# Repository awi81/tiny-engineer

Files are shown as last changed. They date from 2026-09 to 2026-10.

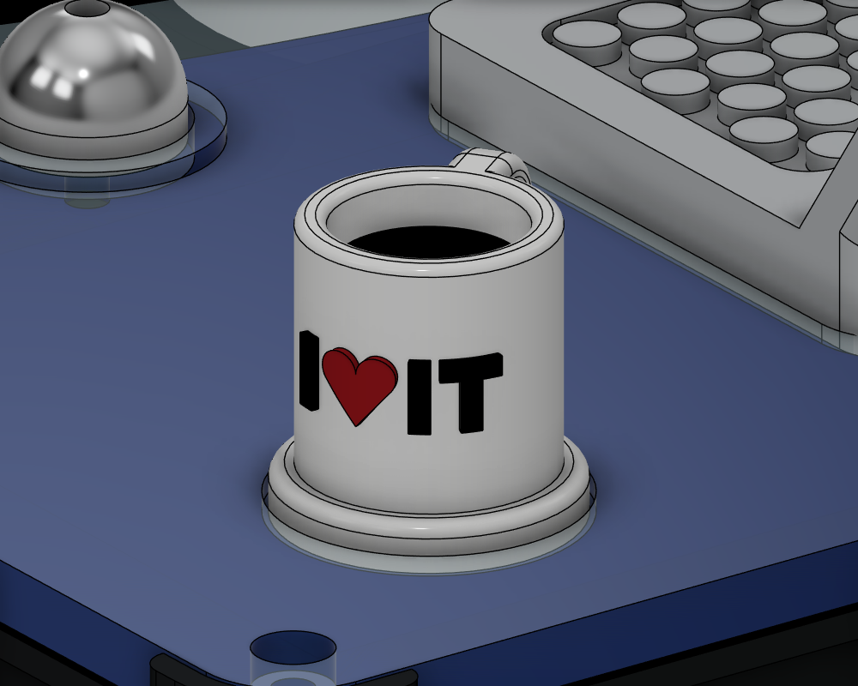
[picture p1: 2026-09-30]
mein-build/farben/variante2-tasse.png

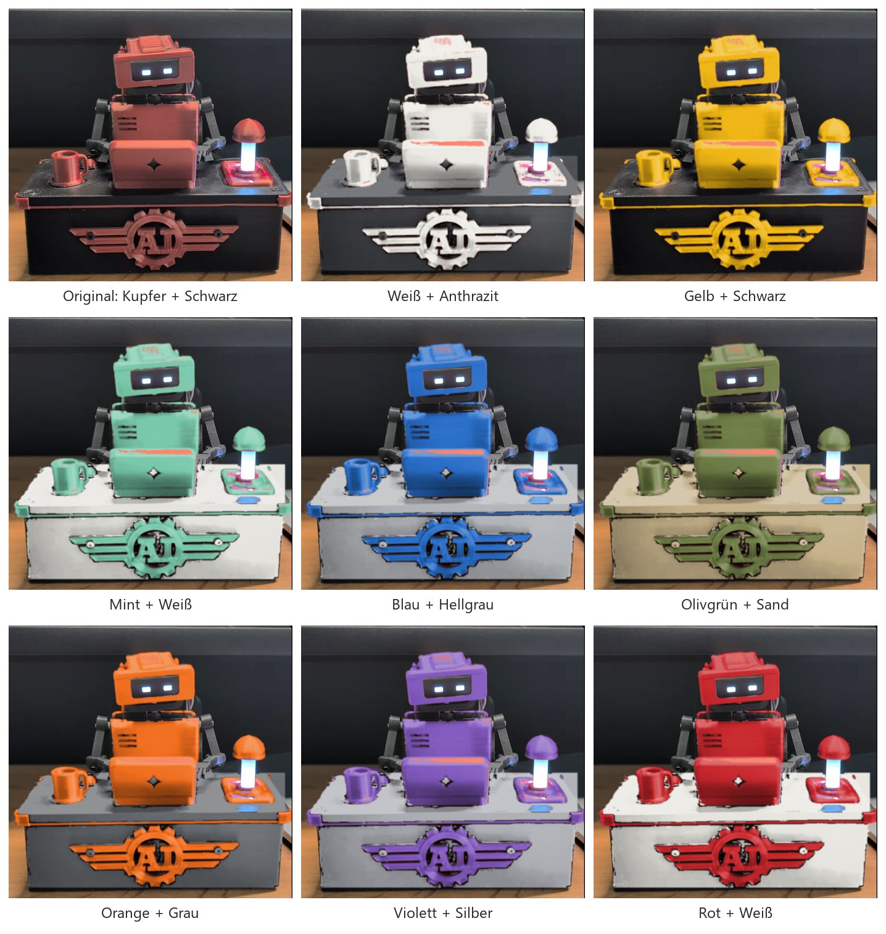
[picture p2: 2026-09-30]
mein-build/farben/farbideen.jpg

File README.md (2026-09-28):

# Tiny Engineer

> Give your AI coding agent a body.

Tiny Engineer demo

Tiny Engineer is an open-source, 3D-printable desktop robot that physically acts out what an AI coding agent is doing: reading, thinking, coding, finishing tasks (with a audio cue). It runs on an ESP32 over Wi-Fi and exposes a simple REST API, so any tool that can make an HTTP request can drive it.

**[Watch the demo](https://youtu.be/RX_QRxdXMjg) · [Build your own](#build-your-own) · [How it works](#how-it-works) · [API](docs/api.md)**

## Why?

AI coding agents increasingly spend long stretches working on their own. I wanted to see what mine was doing without staring at the IDE.

So I built a slightly ridiculous desk robot: instead of another spinner or status line, there is a tiny teammate sitting next to me, visibly reading, thinking, and typing while the agent works.

## How it works

How Tiny Engineer works

An AI agent works; an integration turns that into events; the robot’s REST API on your LAN receives them; the hardware moves and reacts.

**How it connects**

- **Cursor** — Cursor Agent → Cursor hooks → `tiny-engineer-cursor` script → HTTP over Wi-Fi
- **Antigravity CLI** — Antigravity Agent → lifecycle hooks → `tiny-engineer-antigravity` script → HTTP over Wi-Fi
- **Claude Code** — Claude Code → project hooks → `tiny-engineer-claude-code` script → HTTP over Wi-Fi
- **Bring your own** — Codex or any other agent → your script/plugin/app → HTTP REST

All hit the same Tiny Engineer REST API (`/anim`). The ESP32-C3 runs that API, robot logic, and animations, then drives (and plays audio):

| Hardware | Role |
| --- | --- |
| PCA9685 → 5× servos | Head / neck, hands / body |
| Waveshare 0.91inch OLED (SSD1306) | Status, face, info |
| MAX98357A → speaker | Audio |

Cursor is one example client, not the architecture. Details: [Cursor hooks](docs/hooks.md) · [any integration](docs/integration.md) · [HTTP API](docs/api.md)

## Build your own

**Start here:** [docs/getting-started.md](docs/getting-started.md) — thin checklist (shop → print → wire → flash → assemble → wizard → prove → agent).

New to hardware? Optional skim of **[From Code to Circuits](docs/hardware-for-software-engineers/README.md)** — then return to the checklist.

## Hardware overview

Major pieces (exact models and counts in the BOM):

| Role | Part | Qty |
| --- | --- | --- |
| Main Controller | [Waveshare ESP32-C3-Zero](https://www.waveshare.com/esp32-c3-zero.htm) | 1 |
| Servo Controller PWM | [Adafruit PCA9685](https://www.adafruit.com/product/815) | 1 |
| Actuators | Analog micro servos — **Tower Pro SG90 recommended**; Feetech FS0307 for a compact build; Parametrically designed for any standard micro servos | 5 |
| Display | [Waveshare 0.91inch OLED Module](https://www.waveshare.com/0.91inch-oled-module.htm) (SSD1306, 128×32, I2C) | 1 |
| Audio | [MAX98357A](https://www.adafruit.com/product/3006) + [8 Ω / 1 W speaker](https://www.adafruit.com/product/3923) | 1 + 1 |
| USB / power | [Adafruit 5993 USB-C breakout](https://www.adafruit.com/product/5993); **5 V / ≥2 A** supply | 1 |
| Structure | 3D-printed parts | — |

Complete inventory and limits: [docs/hardware/components.md](docs/hardware/components.md). What to buy (cart + which servo): [docs/shopping.md](docs/shopping.md).

> **Interested in an assembled Main Board?**  
> An integrated PCB that replaces most of the separate electronics modules and wiring is in development. If you'd be interested in getting a fully assembled board, [let me know in the community interest check](https://github.com/jamro/tiny-engineer/discussions/50).

## Quick start

Firmware is Arduino on [PlatformIO](https://platformio.org/). From the project root:

```bash
pio run                 # build
pio run -t upload       # flash firmware + LittleFS
pio device monitor      # serial (115200)
```

If servos move but audio is silent, run `pio run -t uploadfs` once.

**Wi-Fi (first boot):** join `TinyEngineer-XXXX`, open `http://192.168.4.1/config`. Wizard: servos, screen orientation, RGB LED, speaker, then a **2.4 GHz** network. OLED shows the join-AP steps.

**Web UI:** `http://tiny-engineer.local/` (or the IP on the OLED) — settings, hardware tests, animations.

**Make it move:**

```bash
curl -X POST "http://tiny-engineer.local/anim?name=ring"
```

Full route list: [docs/api.md](docs/api.md). Settings: [docs/settings.md](docs/settings.md).

## AI integrations

Anything that can `POST` over HTTP can drive the robot:

```bash
curl -X POST "http://tiny-engineer.local/anim?name=typing"
```

Useful `name` values: `typing`, `reading`, `thinking`, `ring`, `welcome`, `wakeup`, `sleep`, `attention`, `error`, `abort`, `dead`, `none`.

Cursor projects can map agent events to poses via hooks — [docs/hooks.md](docs/hooks.md). Broader patterns and examples: [docs/integration.md](docs/integration.md). Optional extra: sleep/wake when you lock or unlock a Mac — [docs/macos-lock-unlock.md](docs/macos-lock-unlock.md).

## Documentation

| Goal | Doc |
| --- | --- |
| Build end-to-end | [docs/getting-started.md](docs/getting-started.md) |
| Flash firmware | [docs/flash.md](docs/flash.md) |
| Parts / cart | [docs/shopping.md](docs/shopping.md) |
| Wiring / power | [docs/hardware/README.md](docs/hardware/README.md) |
| Printable parts | [3d_models/README.md](3d_models/README.md) |
| Optional mods | [mods/README.md](mods/README.md) |
| Assemble printed parts | [docs/3d/assembly.md](docs/3d/assembly.md) |
| Resize CAD for another servo | [docs/3d/parametric-design.md](docs/3d/parametric-design.md) |
| Servo axes / safe ranges | [docs/robot-movement.md](docs/robot-movement.md) |
| HTTP API | [docs/api.md](docs/api.md) |
| Settings | [docs/settings.md](docs/settings.md) |
| Cursor hooks | [docs/hooks.md](docs/hooks.md) |
| Any IDE / REST | [docs/integration.md](docs/integration.md) |
| Firmware / package tests | [docs/testing.md](docs/testing.md) |
| Full index | [docs/README.md](docs/README.md) |

## Build one, break one, share it

Print it, wire it, change the CAD, swap animations, or hook up a different agent. Issues and PRs welcome — especially new integrations. See [CONTRIBUTING.md](CONTRIBUTING.md). Vulnerabilities: [SECURITY.md](SECURITY.md). Conduct: [CODE_OF_CONDUCT.md](CODE_OF_CONDUCT.md).

Tiny Engineer

## License

- **Software** (firmware, integrations, scripts, documentation) — [MIT](LICENSE)
- **Hardware designs** (CAD source and printables in [`3d_models/`](3d_models/) and under [`mods/*/3d_models/`](mods/); KiCad PCBs in [`hardware/`](hardware/)) — [CERN-OHL-S-2.0](3d_models/LICENSE)

See [LICENSING.md](LICENSING.md) for scope and effective date. The **Tiny Engineer** name and logo are not licensed — see [TRADEMARK.md](TRADEMARK.md).

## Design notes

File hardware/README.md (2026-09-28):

# Hardware (PCB)

KiCad PCB projects for Tiny Engineer.

Boards live under `boards/<board-name>/`. Prefer the same name for the directory and the KiCad project.

| Board | Role |
| --- | --- |
| [`main-control-board`](boards/main-control-board/) | Draft main board: PCA9685, MAX98357A, and USB-C on the board; ESP32-C3-Zero plugs into two sockets |

Contribution rules, KiCad version, what to commit, ERC/DRC, and PR expectations: [docs/pcb.md](../docs/pcb.md). Pre-PR checklist: [docs/pcb.md#checklist](../docs/pcb.md#checklist). Critical net checklist: [docs/pcb.md#expected-nets-yml](../docs/pcb.md#expected-nets-yml). Local/CI checks: `python3 scripts/check_pcb.py` (KiCad 10) — [docs/testing.md](../docs/testing.md).

This tree is KiCad source only. Robot electrical reference (pinout, wiring, BOM) is [`docs/hardware/`](../docs/hardware/README.md). Firmware drivers are `src/hardware/`.

## License

Board sources in `boards/` are [CERN-OHL-S-2.0](LICENSE). See [NOTICE](NOTICE) for copyright, Source Location, and product notice requirements.

This README is software documentation and remains under the MIT License — [LICENSING.md](../LICENSING.md).

The **Tiny Engineer** name and logo are not licensed — [TRADEMARK.md](../TRADEMARK.md).

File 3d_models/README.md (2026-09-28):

# 3D models

Printable parts and source CAD for the Tiny Engineer desk robot.

## Source CAD (edit / resize)

The full assembly — all components composed — lives in [`cad/TinyEngineer.f3d`](cad/TinyEngineer.f3d) (Autodesk Fusion). Open that file to adjust the model or adapt it to different hardware sizing (e.g. different servos). Parametric servo sizes and the Fusion add-in: [docs/3d/parametric-design.md](../docs/3d/parametric-design.md).

**Adding a new part** (parametric rules, timeline, `PRINT_LAYOUT`, Servo Configurator, export, optional mods): [docs/3d/adding-parts.md](../docs/3d/adding-parts.md). Optional / community mods: [`mods/`](../mods/).

## Printables

Individual parts are exported under [`parts/{servo_id}/`](parts/). Match the folder to the servos you bought ([which servo](../docs/shopping.md)). `stl/` next to `3mf/` is the same mesh in binary STL. `step/` next to those is CAD interchange (BRep STEP), not a printable mesh for a home slicer.

Two ways to get the mechanical set (same place in the build path):

- **Print yourself** — use the **`.3mf` files in `parts/sg90/3mf/`**, **`parts/fs0307/3mf/`**, or **`parts/hd1370a/3mf/`**. Ready to print in an orientation that does not need supports. **PLA** or **PETG**. Start with [Print first](#print-first).
- **No printer?** — order the aggregated sets from a third-party service: [order printed parts](../docs/3d/order-parts.md). Orders are at your own risk; fit can vary by provider and design revision.

### Print first

**Home printers only.** Print these two small testers from that folder **before** the rest of the set. Do not print the full robot until both fit. Skip this step when ordering from a service (testers alone are rarely worth the min fee + shipping).

1. **`ServoSizingTester.3mf`** — seat a real servo; do not force it. The body should slide, tabs sit, holes line up, and the shaft should have clearance. Tight or loose → sand/ream, or adjust servo CAD params ([parametric design](../docs/3d/parametric-design.md)).
2. **`ScrewSizingTest.3mf`** — M2 screw pilot-hole tolerance. Each hole is marked with its diameter. Drive an M2 screw into each hole and pick the tightest size that still cuts a thread (does not spin freely / slide through). Set Fusion user parameter `screw_thread_diameter` to that marked value, then re-export before printing structural parts. Details: [M2 screw holes](../docs/3d/parametric-design.md#m2-screw-holes).

Assembly uses **M2 screws** that thread directly into the printed PLA/PETG — no glue, no heat-set inserts. Easy to dismount and modify later. Buyer cart (electronics + screw qty + supply): [docs/shopping.md](../docs/shopping.md). Overall build order: [docs/getting-started.md](../docs/getting-started.md). Mechanical procedure: [docs/3d/assembly.md](../docs/3d/assembly.md). Per-step lengths: [screw list](#screws) below.

### Screws

**Spec:** M2 thread-forming (self-tapping) screws for plastic, **pan-head or button-head** — there are no counterbores/countersinks in any part, so heads sit on the plastic surface. CAD default pilot is **2.1 mm** (Fusion user parameter `screw_thread_diameter`); if your `ScrewSizingTest` winner differs, re-export at that diameter before printing structural parts. Details: [M2 screw holes](../docs/3d/parametric-design.md#m2-screw-holes).

**One BOM for every servo preset** (`parts/sg90/`, `parts/fs0307/`, `parts/hd1370a/`, …). Printed parts scale with the servo choice, but the lengths below are the reference list for all of them — including smaller models for smaller servos. Buy quantities: [docs/shopping.md](../docs/shopping.md). Pilots are cut as deep as practical so nearby lengths often work too; if you already have different M2 lengths, test-fit before buying a full set. Per-step placement: [assembly guide](../docs/3d/assembly.md).

**Per robot (qty is source of truth):**

| Item | Qty | Typical use |
| --- | --- | --- |
| M2×4 mm | 8 | Emblem, PCA9685, MAX98357A |
| M2×8 mm | 21 | Hat, Neck↔Head, Chest center (prefer two), Belly↔Chest, LampBase, laptop, mug, Chair↔Desk, elbows |
| M2×16 mm | 15 | Chest side servos, SeatLeft/Right, DeskTop stack, USB-C, Bell |
| M2 nuts | 6 | Neck captured ×1, USB-C ×4, Bell ×1 |
| Servo bag screws | 5 | Neck shaft, Neck↔Head (robot’s left), Belly shaft, both arms |

Prefer **two** M2×8 for the Neck servo in `Chest`; one at the back is enough if space is tight (buy 21 either way). An M2 assortment covering **M2×4–M2×16** is the easy path.

## Parts

Same filenames in each `parts/{servo_id}/3mf/` folder (and matching `stl/` / `step/`):

| File | Role |
| --- | --- |
| `PartsSetA.3mf` | Aggregated copper-color group for [service orders](../docs/3d/order-parts.md) (home print: use individuals below) |
| `PartsSetB.3mf` | Aggregated black-color group for [service orders](../docs/3d/order-parts.md) (home print: use individuals below) |
| `Head.3mf` | Head (pitch) |
| `Neck.3mf` | Neck (yaw) |
| `ForearmLeft.3mf` | Left forearm / hand |
| `ForearmRight.3mf` | Right forearm / hand |
| `UpperArm.3mf` | Upper arm |
| `Chest.3mf` | Chest / torso |
| `Belly.3mf` | Belly |
| `Chair.3mf` | Chair |
| `SeatLeft.3mf` | Left chair seat |
| `SeatRight.3mf` | Right chair seat |
| `Desk.3mf` | Desk structure |
| `DeskTop.3mf` | Desk top surface |
| `DeskPad.3mf` | Desk pad |
| `LaptopCase.3mf` | Miniature laptop body |
| `LaptopScreen.3mf` | Laptop screen |
| `Bell.3mf` | Service bell |
| `LampBase.3mf` | Desk lamp base |
| `LampCap.3mf` | Lamp cap |
| `LampDiffuser.3mf` | Lamp diffuser |
| `LampButton.3mf` | Lamp button |
| `Mug.3mf` | Mug |
| `Coffee.3mf` | Coffee fill |
| `Hat.3mf` | Hat |
| `ServoSizingTester.3mf` | Servo pocket fit tester |
| `ScrewSizingTest.3mf` | M2 screw pilot-hole diameter tester |
| `AiEmblem.3mf` | AI emblem detail |

## Next steps

Return to the build checklist: [docs/getting-started.md](../docs/getting-started.md) ([§2 Print or order](../docs/getting-started.md#2-print-or-order) done). Wire and flash **before** opening the mechanical guide.

1. Wire, then flash: [docs/hardware/wiring.md](../docs/hardware/wiring.md), [docs/flash.md](../docs/flash.md)
2. Assemble in one run: [docs/3d/assembly.md](../docs/3d/assembly.md)
3. Servo axes and safe ranges: [docs/robot-movement.md](../docs/robot-movement.md)
4. Bring-up and failures: [docs/hardware/testing.md](../docs/hardware/testing.md)

## License

CAD source (`.f3d`) in [`cad/`](cad/) and printable parts (`.3mf`) in [`parts/`](parts/) are licensed under [CERN-OHL-S-2.0](LICENSE). See [NOTICE](NOTICE) for copyright, Source Location, and product notice requirements.

Commercial use is allowed. If you modify and distribute Products based on these designs, reciprocal provisions require sharing your Complete Source under the same license. This documentation file is software documentation and remains under the MIT License — see [LICENSING.md](../LICENSING.md).

The **Tiny Engineer** name and logo are not licensed — see [TRADEMARK.md](../TRADEMARK.md).

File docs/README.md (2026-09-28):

# Docs index

Pick a path. Depth lives in the linked pages.

### Building the robot

| You want to… | Start here |
| --- | --- |
| **Build from scratch** (canonical checklist) | [getting-started.md](getting-started.md) |
| **Buy parts** (one cart) | [shopping.md](shopping.md) |
| **Bridge into hardware/electronics** (software engineer background) | [hardware-for-software-engineers/README.md](hardware-for-software-engineers/README.md) — optional parallel reading; safety card lives on the checklist |
| **Assemble printed parts** (mechanical procedure) | [3d/assembly.md](3d/assembly.md) |
| **Flash firmware** | [flash.md](flash.md) |
| **Wire / power detail** | [hardware/wiring.md](hardware/wiring.md) → [hardware/README.md](hardware/README.md) |
| **Print / parts inventory** | [../3d_models/README.md](../3d_models/README.md) |
| **Order printed parts** (no 3D printer) | [3d/order-parts.md](3d/order-parts.md) |
| **Adapt CAD to a different servo** | [3d/parametric-design.md](3d/parametric-design.md) |
| **Add a new CAD / printable part** | [3d/adding-parts.md](3d/adding-parts.md) |
| **Optional mods** | [../mods/README.md](../mods/README.md) |
| **Use with an agent** (robot already on Wi-Fi) | [integration.md](integration.md) · Cursor: [hooks.md](hooks.md) |

### Reference and contribute

| You want to… | Start here |
| --- | --- |
| **Contribute a PCB** (KiCad) | [pcb.md](pcb.md) → [`hardware/`](../hardware/README.md) |
| **HTTP API / settings** | [api.md](api.md); add a setting: [settings.md](settings.md) |
| **Any IDE / scripts** | [integration.md](integration.md) |
| **Firmware / package tests** | [testing.md](testing.md) |
| **AI coding agents (repo rules)** | [AGENTS.md](../AGENTS.md) |
| **Contribute / report a vuln** | [CONTRIBUTING.md](../CONTRIBUTING.md); [SECURITY.md](../SECURITY.md) |

Also: [robot-movement.md](robot-movement.md) (servo axes and safe ranges); optional [macos-lock-unlock.md](macos-lock-unlock.md) (sleep/wake on Mac screen lock).

**Source of truth:** pin constants in firmware (`include/pins.h`); electrical detail in `docs/hardware/`; HTTP shapes in [api.md](api.md). Overall build order: [getting-started.md](getting-started.md).

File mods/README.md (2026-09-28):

# Mods

Optional add-ons for Tiny Engineer. Stock robot parts live in [`3d_models/`](../3d_models/).

A mod can hold models and anything else (notes, images, firmware snippets). Printable geometry and Fusion source stay under that mod’s `3d_models/` folder.

## Layout

```text
mods/<mod_name>/
  README.md              # optional: what it is, non-model notes
  3d_models/
    cad/                 # Fusion source, when the mod has one
    parts/{servo_id}/    # exports; same idea as 3d_models/parts/
  ...                    # anything that is not a model
```

`parts/{servo_id}/` mirrors stock: `3mf/`, `stl/`, and `step/`. Example: [`halloween/`](halloween/).

## Audio

Optional speaker replacements live in `mods/<mod_name>/assets/`. Format matches stock: **44100 Hz, mono, 16-bit PCM**. Firmware still plays `/welcome.wav` and the other root names. The build overlay copies stock [`assets/`](../assets/) first, then overwrites any basename the mod ships. A missing file stays the stock clip.

Set the mod in [`platformio.ini`](../platformio.ini) (`custom_audio_mod = halloween`) and flash with `pio run -t upload`. An empty option keeps the stock image. How to flash: [docs/flash.md](../docs/flash.md).

Clips with phrase marks (`welcome`, `attention`, `error`, `abort`, `dead`) need a sibling `.cue` next to the replacement WAV. `bell` has no marks. A cue without its WAV is rejected. Lines are `key=ms` (`#` comments allowed). `end_ms` must be within 200 ms of the WAV duration, phases must increase, and a blink must sit inside its window. The pack step checks this before the image is built.

Firmware loads `/welcome.cue` (and the other clip names) from LittleFS at boot. A missing or invalid file keeps the stock marks compiled into the firmware. Editing a `.cue` and running `pio run -t uploadfs` changes timing without a gesture-code change.

| Clip | Keys, in phase order |
| --- | --- |
| `welcome` | `greeting_end_ms`, `pause_end_ms`, `question_end_ms`, `end_ms`. Blink: `blink_start_ms`, `blink_end_ms` inside greeting→pause. |
| `attention` | `pst_end_ms`, `human_end_ms`, `end_ms`. Blink inside pst→human. |
| `error` | `uhoh_end_ms`, `human_end_ms`, `problem_end_ms`, `end_ms` |
| `abort` | `fine_end_ms`, `didnt_want_end_ms`, `finish_end_ms`, `end_ms` |
| `dead` | `dense_ms`, `shutdown_ms`, `end_ms` |

## Workflow

Design, timeline, `PRINT_LAYOUT`, export, and checklist: [docs/3d/adding-parts.md](../docs/3d/adding-parts.md).

## Commits

`type(mods): summary`. Name the mod in the summary (`feat(mods): add desk clamp`). One scope for every mod. `feat(mods)` / `fix(mods)` do not version the stock CAD revision. Moving a mod into stock [`3d_models/cad/`](../3d_models/cad/) and [`3d_models/parts/`](../3d_models/parts/) is `feat(cad)`. Full rules: [CONTRIBUTING.md](../CONTRIBUTING.md).

## License

CAD and manufacturing exports under `mods/<mod_name>/3d_models/{cad,parts}/` are [CERN-OHL-S-2.0](../3d_models/LICENSE). See [NOTICE](../3d_models/NOTICE) for warranty and product-notice requirements.

When you distribute a Product based on a mod, cite that licence and use the mod’s own `3d_models` tree as the Source Location (for example `https://github.com/jamro/tiny-engineer/tree/main/mods/halloween/3d_models`).

This README and other files beside `3d_models/` are documentation under the [MIT License](../LICENSE).

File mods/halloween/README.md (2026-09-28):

# Halloween

Optional Halloween mod for Tiny Engineer: a pumpkin head, a lamp, and cauldron pieces. Printable parts and Fusion source are under [`3d_models/`](3d_models/).

## Audio

Alternate speaker clips are in [`assets/`](assets/). The set replaces `welcome`, `attention`, `error`, and `abort`. `bell` and `dead` stay the stock files. Transcripts and cue marks are in [`assets/README.md`](assets/README.md).

Build and flash this overlay with `custom_audio_mod = halloween` in [`platformio.ini`](../../platformio.ini), then `pio run -t upload`. See [docs/flash.md](../../docs/flash.md).

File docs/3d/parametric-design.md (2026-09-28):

# Parametric design (different servo sizes)

[`3d_models/cad/TinyEngineer.f3d`](../../3d_models/cad/TinyEngineer.f3d) is the parametric Fusion source for the robot. Printed pockets, mounting tabs, shaft clearance, and M2 screw pilots are driven by Fusion **user parameters**. Change those values and the assembly rebuilds for a different micro servo or a tighter/looser screw fit.

Presets live in [`servos.json`](../../3d_models/fusion/TinyEngineerTools/servos.json). **TinyEngineer Tools** writes them into the `.f3d`, then exports print meshes under `parts/{servo_id}/3mf/` (and matching `stl/`) plus STEP CAD under `parts/{servo_id}/step/`.

```mermaid
flowchart LR
  json["servos.json presets"]
  cfg["Servo Configurator"]
  f3d["TinyEngineer.f3d user params"]
  parts["parts/servo_id meshes"]
  json --> cfg --> f3d --> parts
```

## Which servo

Servo size sets the size of the **whole robot**. Desk, chair, body, and pockets all scale with the preset. Pick the servo first, then print the matching `parts/{servo_id}/3mf/` folder.

Built-in presets in [`servos.json`](../../3d_models/fusion/TinyEngineerTools/servos.json):

| Model | `servo_id` | When to use |
| --- | --- | --- |
| **Tower Pro SG90** (recommended) | `sg90` | Easiest to buy. Bigger desk — electronics are easier to fit and assemble. |
| **Feetech FS0307** | `fs0307` | More compact. Looks better if you want a smaller robot. |
| **PowerHD HD-1370A** | `hd1370a` | Still supported for backward compatibility. Not the pick for a new build. |

A non-standard servo is fine: measure it, add a preset, run the configurator ([Add a new servo](#add-a-new-servo)). Print parts that match that `servo_id`.

Print matching `parts/{servo_id}/3mf/`: [`sg90`](../../3d_models/parts/sg90/3mf/), [`fs0307`](../../3d_models/parts/fs0307/3mf/), [`hd1370a`](../../3d_models/parts/hd1370a/3mf/).

## Servo parameters

Each preset in `servos.json` is a map of Fusion user-parameter names to expressions such as `"20 mm"`. The configurator ([`servo.py`](../../3d_models/fusion/TinyEngineerTools/servo.py)) writes those into the open design. It refuses names that are not already user parameters in the `.f3d` — do not invent keys.

Servo body dimensions used as Fusion user parameters

### Body and tabs

| Parameter | Meaning |
| --- | --- |
| `servo_body_width` | Body length between the two mounting tabs (tabs not included). |
| `servo_body_height` | Body height, from the mounting-tab plane to the opposite face. |
| `servo_body_depth` | Body thickness (front to back). |
| `servo_mount_width` | How far each mounting tab sticks out from the body. |
| `servo_mount_thickness` | Tab thickness. |

### Gearbox and shaft stack

| Parameter | Meaning |
| --- | --- |
| `servo_gearbox_height` | Gearbox step sitting on the body. |
| `servo_shaft_housing_height` | Boss around the output shaft, above the gearbox. |
| `servo_gearbox_padding` | How far the gearbox / shaft stack is inset from the body edge (the asymmetric “fat” side of typical micro servos). |

### Shaft

| Parameter | Meaning |
| --- | --- |
| `servo_shaft_position` | Distance from the body end to the shaft axis. |
| `servo_shaft_length` | How far the spline shaft sticks out. |
| `servo_shaft_radius` | Shaft radius (not diameter). |

### Mount holes

`servo_mount_hole_radius` is in `servos.json` but not drawn on the diagram.

| Parameter | Meaning |
| --- | --- |
| `servo_mount_hole_depth_offset` | Hole shift along body depth from the tab centerline. |
| `servo_mount_hole_width_offset` | Hole shift along the tab (toward or away from the body). |
| `servo_mount_hole_radius` | Screw-hole radius in the tabs. |

### Not a dimension

| Parameter | Meaning |
| --- | --- |
| `servo_id` | Short lowercase folder id (`hd1370a`, `fs0307`, `sg90`). The configurator writes it; the exporter uses it. |

## M2 screw holes

Assembly uses **M2 screws** that thread directly into the printed PLA/PETG (no heat-set inserts). Pilot-hole size is a Fusion **user parameter**, not a servo preset:

| Parameter | Meaning |
| --- | --- |
| `screw_thread_diameter` | Modeled diameter of M2 self-tapping pilot holes in the printed parts. |

Related (usually leave alone): `screw_head_diameter`, `screw_head_height` — countersink / head clearance for the same fasteners.

`screw_thread_diameter` is **not** in [`servos.json`](../../3d_models/fusion/TinyEngineerTools/servos.json). Change it in Fusion (**Modify → Change Parameters**), then run **Tiny Engineer Parts Exporter** again.

### Why dial it in

Print tolerances vary by printer, material, and slicer. FDM holes often print smaller than modeled, so the CAD default is slightly oversized relative to an M2 major diameter (~2.0 mm). On some printers the hole still comes out large enough that the screw **slides through** instead of cutting a thread — mounting gets loose.

### Use `ScrewSizingTest` first

1. Print [`ScrewSizingTest.3mf`](../../3d_models/README.md#print-first) from your `parts/{servo_id}/3mf/` folder (quick, small).
2. Each hole is labeled with its diameter (about **2.00–2.40 mm** in **0.05 mm** steps).
3. Drive an M2 screw into each hole. Prefer the **tightest** hole that still lets the screw cut a clean thread (firm bite, not free-spinning, not so tight you strip the plastic).
4. Set `screw_thread_diameter` to that labeled value and re-export before printing the full set.

Print [`ServoSizingTester`](../../3d_models/README.md#print-first) in the same “print first” pass for servo pocket fit.

### Recommended / tested values

| Value | When |
| --- | --- |
| **2.1 mm** | CAD default and shipped `parts/*/3mf/` exports. Tested path on a **Creality Ender 3 V3 SE**, PLA, ~0.16 mm layer height ([printing notes](../hardware-for-software-engineers/06-3d-printing-and-mechanical-build.md)). |
| Smaller (e.g. 2.05–2.15 mm) | Pilot too tight to start a thread without cracking — pick from `ScrewSizingTest`. |
| Larger (e.g. 2.25–2.35 mm) | Screws feel loose / slide through on your printer — pick from `ScrewSizingTest`. |

Always trust **your** `ScrewSizingTest` result over the table if they disagree.

## TinyEngineer Tools add-in

**TinyEngineer Tools** is a Fusion add-in for [`cad/TinyEngineer.f3d`](../../3d_models/cad/TinyEngineer.f3d). It writes servo dimensions from [`TinyEngineerTools/servos.json`](../../3d_models/fusion/TinyEngineerTools/servos.json) into Fusion user parameters, and exports selected `PRINT_LAYOUT` children as `.3mf` / binary `.stl` / `.step` (PRINT_LAYOUT with one child visible, so captured print pose stays). STL/3MF use Save as Mesh; STEP uses File → Export.

Fusion must know about the add-in folder. Folder name, `TinyEngineerTools.py`, and `TinyEngineerTools.manifest` must stay the same.

Official Autodesk steps: [How to install an add-in or script](https://www.autodesk.com/support/technical/article/caas/sfdcarticles/sfdcarticles/How-to-install-an-ADD-IN-and-Script-in-Fusion-360.html).

### Point Fusion at this repo

Fusion remembers the path. Code stays in git. Reload after edits (see below).

1. Open Fusion.
2. Open **Utilities → Add-Ins → Scripts and Add-Ins**. Shortcut: **Shift+S**.
3. Open the **Add-Ins** tab.
4. Click the green **+** next to **Script of add-in from device**.
5. Browse to `3d_models/fusion/TinyEngineerTools/` in this repo and select the folder.
6. Select **TinyEngineerTools** in the list and click **Run**.
7. Optional: enable **Run on Startup** so Fusion starts it every launch.

### Use the commands

Open [`cad/TinyEngineer.f3d`](../../3d_models/cad/TinyEngineer.f3d) and stay in the **Design** workspace. Both commands live under **Utilities → Add-ins**.

#### TinyEngineer Servo Configurator

Select a servo model and apply dimensions, including `servo_id` (short lowercase id such as `sg90`).

The command reads [`servos.json`](../../3d_models/fusion/TinyEngineerTools/servos.json), previews the values, and writes them into the design’s user parameters. Use this to preview a preset in the open design; Parts Exporter can also apply selected servos during export.

#### Tiny Engineer Parts Exporter

A command dialog asks what to export (all checkboxes **on** by default):

* **Servos** — each preset in [`servos.json`](../../3d_models/fusion/TinyEngineerTools/servos.json)
* **Parts** — each direct `PRINT_LAYOUT` child in a scrollable table, with **Select all** / **Deselect all**
* **Formats** — `3MF`, `STL`, `STEP`

Then choose an export folder.

For each selected servo the add-in applies that preset’s parameters, then exports each selected part separately. For each part it temporarily hides the others, keeps that child visible in its saved print orientation, and writes the checked formats under that servo’s folder:

* `{servo_id}/3mf/{name}.3mf` (if 3MF selected)
* `{servo_id}/stl/{name}.stl` binary STL (if STL selected)
* `{servo_id}/step/{name}.step` STEP CAD via File → Export (if STEP selected)
* `{servo_id}/README.md` with that servo’s parameters from `servos.json`

After the run, visibility and the design’s previous servo parameters are restored. A progress dialog stays up so Fusion can paint; Cancel stops after the current part.

### Keyboard cut after a servo change

The extrude after the `keyboard` sketch cuts the deck around the keys: one profile whose inner loops are the key outlines. When a larger servo grows the key grid, Fusion also maps the new key profiles into that cut, so those keys disappear ([#31](https://github.com/jamro/tiny-engineer/issues/31)).

Servo Configurator and Parts Exporter (including the parameter restore after export) re-select the deck profile — the one with the most loops — after every preset change (`fix_keyboard_cut()` in [`servo.py`](../../3d_models/fusion/TinyEngineerTools/servo.py)). If you change servo parameters by hand in **Modify → Change Parameters**, edit that extrude and select only the deck profile.

## Add a new servo

1. Measure a real unit (prefer calipers over datasheet marketing sizes).
2. Copy an existing object in [`servos.json`](../../3d_models/fusion/TinyEngineerTools/servos.json); keep the same keys; set a unique `servo_id`.
3. Reload the add-in, run Servo Configurator, confirm Fusion parameters update.
4. Print [`ServoSizingTester`](../../3d_models/README.md#print-first) and [`ScrewSizingTest`](../../3d_models/README.md#print-first) first (servo pocket + M2 pilot), then export.

The configurator refuses unknown Fusion parameter names. Do not invent keys that are not already user parameters in the `.f3d`.

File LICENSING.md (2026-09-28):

# Licensing

This repository contains both software and hardware design files. They are licensed separately.

## Software — MIT License

The following are licensed under the [MIT License](LICENSE):

| Path | Contents |
| --- | --- |
| `src/`, `include/`, `lib/`, `test/` | Firmware |
| `packages/`, `scripts/`, `package.json` | Integrations and tooling |
| `data/`, `assets/` | Firmware filesystem assets |
| `docs/` | Documentation (including wiring diagrams and hardware guides) |
| `.cursor/` | Cursor hook configuration |
| `platformio.ini`, `partitions.csv` | Build configuration |
| All other repository files | Unless explicitly listed under hardware below |

## Hardware designs — CERN-OHL-S-2.0

Mechanical CAD, printable manufacturing outputs, and PCB sources are licensed under the [CERN Open Hardware Licence Version 2 — Strongly Reciprocal (CERN-OHL-S-2.0)](3d_models/LICENSE):

| Path | Contents |
| --- | --- |
| `3d_models/cad/` | Source CAD (`.f3d`) |
| `3d_models/parts/` | Printable part exports (`.3mf`) |
| `mods/*/3d_models/cad/`, `mods/*/3d_models/parts/` | Mod CAD and manufacturing exports |
| `hardware/boards/` | KiCad PCB projects |

Commercial use of these hardware designs is allowed. If you modify and distribute Products based on these designs, the reciprocal provisions of CERN-OHL-S-2.0 require that you make the corresponding Complete Source available under the same license. See [3d_models/LICENSE](3d_models/LICENSE), [3d_models/NOTICE](3d_models/NOTICE), [hardware/LICENSE](hardware/LICENSE), and [hardware/NOTICE](hardware/NOTICE) for copyright, warranty disclaimer, and Source Location details.

Documentation in `3d_models/README.md`, `mods/README.md`, and `hardware/README.md` is software documentation and remains under the MIT License. Other files beside a mod’s `3d_models/` folder are MIT as well.

### Source Location

Canonical mechanical design source:

`https://github.com/jamro/tiny-engineer/tree/main/3d_models`

Optional mod CAD and exports use that mod’s `3d_models` tree (for example `https://github.com/jamro/tiny-engineer/tree/main/mods/halloween/3d_models`).

Canonical PCB design source:

`https://github.com/jamro/tiny-engineer/tree/main/hardware`

When distributing a specific revision, link to the corresponding tagged release or commit (for example, `https://github.com/jamro/tiny-engineer/tree/v0.1.0/3d_models`).

## Trademarks

The **Tiny Engineer** name and logo are **not** licensed under either MIT or CERN-OHL-S-2.0. See [TRADEMARK.md](TRADEMARK.md).

## Machine-readable license mapping

Per-path SPDX annotations are in [REUSE.toml](REUSE.toml).

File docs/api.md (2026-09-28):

# HTTP API

JSON HTTP server on the ESP32-C3. Source: [`src/http/http_server.cpp`](../src/http/http_server.cpp) and handlers under [`src/http/`](../src/http/), test routes in [`src/http/test_handlers.cpp`](../src/http/test_handlers.cpp).

Listens on **port 80** after STA Wi-Fi connects, or during setup AP mode at `http://192.168.4.1/`. Base URL is the board IP (OLED / serial) or `http://tiny-engineer.local` (mDNS, 2.4 GHz only).

Optional auth: when an `access_token` is configured in settings, all JSON API routes require `Authorization: Bearer <token>`. Empty token (default) means no auth. `GET /auth` is always public and reports whether auth is required. Missing/wrong token → **401** `{"ok":false,"error":"unauthorized"}`. HTML panel routes stay public (the UI prompts for the token). `Content-Type: application/json`. CORS: `Access-Control-Allow-Origin: *`, `Access-Control-Allow-Headers: Authorization`.

When WiFi credentials are not saved yet, control APIs (`/anim`, `/test/*`) return **503** `{"ok":false,"error":"wifi not configured"}`. Setup routes (`/`, `/config`, `/auth`, `/health`, `/settings`, `/setup/servo`, `/setup/led`, `/setup/audio`, `/setup/oled`) stay available on the setup AP.

If boot WiFi credentials are missing, the device opens setup AP mode (`TinyEngineer-XXXX`) and serves a five-step setup wizard at `/config` (servo calibration, OLED orientation, RGB LED, speaker test, then Wi-Fi). If saved credentials fail, it reopens setup AP mode. Hardware tests: [`docs/hardware/testing.md`](hardware/testing.md). How to wire this API into AI tools: [`integration.md`](integration.md).

Firmware answers mDNS A and AAAA (IPv6 link-local) so macOS does not wait 2–3s on a missing AAAA. If a client still pauses on the hostname, force IPv4 (`curl -4`). The IP on the OLED skips DNS entirely.

## Endpoints

### `GET /`

HTML endpoint index. Lists all routes plus supported parameters for `/anim`, `/settings`, `/test/servo`, `/setup/servo`, `/setup/led`, `/setup/audio`, and `/setup/oled`. Safe, no hardware side effects. Always public (no Bearer required).

Open in a browser:

```bash
curl http://tiny-engineer.local/
```

Returns `Content-Type: text/html; charset=utf-8`.

### `GET /auth`

Whether API auth is required. Always public. Safe, no hardware side effects. Does not reveal the token.

```bash
curl http://tiny-engineer.local/auth
```

```json
{ "ok": true, "required": false, "wifi_configured": true, "provisioning": false }
```

| Field | Meaning |
| --- | --- |
| `ok` | Always `true` on this route |
| `required` | `true` when a non-empty access token is configured |
| `wifi_configured` | `true` when WiFi credentials are saved in NVS |
| `provisioning` | `true` when the setup AP is active |

### `GET /health`

Health. Safe, no hardware side effects. Uses live `WiFi.status()`, not the boot-time flag. Requires Bearer when auth is enabled.

```bash
curl http://tiny-engineer.local/health
curl -H "Authorization: Bearer YOUR_TOKEN" http://tiny-engineer.local/health
```

```json
{
  "ok": true,
  "uptime_ms": 12345,
  "free_heap": 120000,
  "heap_size": 320000,
  "cpu_temp_c": 41.2,
  "wifi": {
    "connected": true,
    "ip": "192.168.1.10",
    "rssi": -42,
    "hostname": "tiny-engineer.local"
  },
  "wifi_configured": true,
  "provisioning": false,
  "setup_ap_ssid": "",
  "setup_ap_ip": "",
  "oled": true
}
```

| Field | Meaning |
| --- | --- |
| `ok` | Always `true` on this route |
| `uptime_ms` | `millis()` since boot |
| `free_heap` | `ESP.getFreeHeap()` — bytes available for allocation |
| `heap_size` | `ESP.getHeapSize()` — total heap bytes; usage % = `(1 - free_heap / heap_size) × 100` |
| `cpu_temp_c` | ESP32-C3 on-die temperature in °C (not ambient); `null` if the sensor is unavailable |
| `wifi.connected` | `WiFi.status() == WL_CONNECTED` |
| `wifi.ip` | STA IPv4, or `""` if down |
| `wifi.rssi` | dBm, or `0` if down |
| `wifi.hostname` | mDNS name from settings (`{hostname}.local`, default `tiny-engineer.local`) |
| `wifi_configured` | `true` when WiFi credentials are saved in NVS |
| `provisioning` | `true` when setup AP mode is active |
| `setup_ap_ssid` | Setup AP SSID when `provisioning` is true, else `""` |
| `setup_ap_ip` | Setup AP IP when `provisioning` is true (usually `192.168.4.1`), else `""` |
| `oled` | SSD1306 probed and initialized |

### `GET /settings`

Persistent settings from NVS. Safe, no hardware side effects. Developer guide for adding settings: [`settings.md`](settings.md).

```bash
curl http://tiny-engineer.local/settings
```

```json
{
  "ok": true,
  "sleep_timeout": 10,
  "hostname": "tiny-engineer",
  "volume": 70,
  "welcome": true,
  "serial_log": false,
  "continuous_timeout": 5,
  "loading": "progress",
  "eyes_style": "classic",
  "access_token_set": false,
  "wifi_configured": true,
  "wifi_ssid": "MyNetwork",
  "wifi_password_set": true,
  "servo_mins": [60, 40, 45, 35, 40],
  "servo_maxs": [130, 130, 135, 125, 130],
  "rgb_order": "GRB",
  "oled_rotate_180": false
}
```

| Field | Meaning |
| --- | --- |
| `sleep_timeout` | Minutes of continuous animation `none` before OLED blanks (default **10**). Any non-idle animation keeps the device awake and restarts the idle clock when returning to `none`. Other APIs do not affect the timer. |
| `hostname` | DHCP/mDNS label without `.local` (default **`tiny-engineer`**) |
| `volume` | Speaker gain percent for tones and WAV playback (default **70**) |
| `welcome` | Play welcome animation on boot when Wi-Fi connects (default **true**). Also enables head/neck motion during `sleep_inertia` loading |
| `serial_log` | USB serial debug logging (default **false**). When off, diagnostic `Serial` output is suppressed |
| `continuous_timeout` | Minutes a continuous animation (`typing` / `reading` / `thinking`) may run before the firmware switches to `attention` then idle (default **5**) |
| `loading` | Boot loading screen: `progress` (bar + large IP for 3 s) or `sleep_inertia` (eyes wake; no bar/IP). Default **`progress`**. Applies on **next reboot** |
| `eyes_style` | OLED eyes look: `classic` (procedural rounded eyes), `kaomoji` (animated faces), `cover` (full-half bars for an eye-hole mask), or `dots` (12×12 circles). Default **`classic`**. Applies **immediately**. Classic, cover, and dots sequences are described under [`POST /anim`](#post-anim); kaomoji face mapping is under [Kaomoji eyes](#kaomoji-eyes); cover drawing is under [Cover eyes](#cover-eyes); dots drawing is under [Dots eyes](#dots-eyes) |
| `access_token_set` | `true` when a non-empty access token is stored (secret itself is never returned) |
| `wifi_configured` | `true` when a WiFi SSID is saved |
| `wifi_ssid` | Saved network name (password is never returned) |
| `wifi_password_set` | `true` when a non-empty WiFi password is saved |
| `servo_mins` | Per-joint safe minimum degrees `[head, neck, left, right, body]` (stock defaults **60, 40, 45, 35, 40**) |
| `servo_maxs` | Per-joint safe maximum degrees (stock defaults **130, 130, 135, 125, 130**). Each max must be greater than the matching min |
| `rgb_order` | Onboard WS2812 wire-byte order (`RGB`, `RBG`, `GRB`, `GBR`, `BRG`, `BGR`). Default **`GRB`**. Survives factory reset |
| `oled_rotate_180` | OLED 180° rotation (`true` → `setRotation(2)`). Default **`false`**. Setup AP only. Survives factory reset |

### `POST /settings`

Update one or more settings. Query params. Values are written to NVS. `sleep_timeout`, `volume`, `welcome`, `serial_log`, `continuous_timeout`, `eyes_style`, and `access_token` apply immediately; a changed `hostname` or `loading` takes effect on the **next reboot**. WiFi credentials (`wifi_ssid` + `wifi_password`) are accepted **only in setup AP mode**; they are **tested before save**; on success the device connects to the home network and returns `wifi_connect_success`, `wifi_ip`, and `wifi_hostname`. `hostname` may be sent with those WiFi params (same validation as Config); it is saved before the STA connect so mDNS uses the chosen name immediately. Outside setup AP → **400** `wifi setup only in AP mode`. Servo ranges (`servo_mins` + `servo_maxs`) are also **setup AP only**; they apply immediately to motion clamps. Outside setup AP → **400** `servo setup only in AP mode`. RGB LED mapping (`rgb_order`) is **setup AP only** and applies immediately to the onboard LED. Outside setup AP → **400** `rgb setup only in AP mode`. OLED rotation (`oled_rotate_180`) is **setup AP only** and applies immediately to the display. Outside setup AP → **400** `oled setup only in AP mode`. Requires Bearer when auth is enabled.

```bash
curl -X POST "http://tiny-engineer.local/settings?sleep_timeout=2"
curl -X POST "http://tiny-engineer.local/settings?hostname=desk-bot"
curl -X POST "http://tiny-engineer.local/settings?volume=40"
curl -X POST "http://tiny-engineer.local/settings?welcome=0"
curl -X POST "http://tiny-engineer.local/settings?serial_log=1"
curl -X POST "http://tiny-engineer.local/settings?continuous_timeout=10"
curl -X POST "http://tiny-engineer.local/settings?loading=sleep_inertia"
curl -X POST "http://tiny-engineer.local/settings?eyes_style=kaomoji"
curl -X POST "http://tiny-engineer.local/settings?access_token=secret"
curl -X POST "http://tiny-engineer.local/settings?access_token="
curl -X POST "http://192.168.4.1/settings?wifi_ssid=MyNetwork&wifi_password=secret&hostname=desk-bot"
curl -X POST "http://192.168.4.1/settings?servo_mins=60,40,45,35,40&servo_maxs=130,130,135,125,130"
curl -X POST "http://192.168.4.1/settings?rgb_order=GRB"
curl -X POST "http://192.168.4.1/settings?oled_rotate_180=1"
curl -X POST "http://tiny-engineer.local/settings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"
```

```json
{
  "ok": true,
  "sleep_timeout": 1,
  "hostname": "desk-bot",
  "volume": 70,
  "welcome": true,
  "serial_log": false,
  "continuous_timeout": 5,
  "loading": "progress",
  "eyes_style": "classic",
  "access_token_set": true,
  "wifi_configured": true,
  "wifi_ssid": "MyNetwork",
  "wifi_password_set": true,
  "servo_mins": [60, 40, 45, 35, 40],
  "servo_maxs": [130, 130, 135, 125, 130],
  "rgb_order": "GRB",
  "oled_rotate_180": false,
  "wifi_connect_success": true,
  "wifi_ip": "192.168.1.10",
  "wifi_hostname": "desk-bot.local",
  "reboot_required": true
}
```

| Param | Type | Range |
| --- | --- | --- |
| `sleep_timeout` | integer | 1–1440 minutes (positive) |
| `hostname` | string | 1–31 chars, `[A-Za-z0-9-]`, not starting/ending with `-` |
| `volume` | integer | 0–100 percent |
| `welcome` | integer | `0` or `1` (boot welcome animation) |
| `serial_log` | integer | `0` or `1` (USB serial debug logging) |
| `continuous_timeout` | integer | 1–1440 minutes (positive) |
| `loading` | string | `progress` or `sleep_inertia` |
| `eyes_style` | string | `classic`, `kaomoji`, `cover`, or `dots` |
| `access_token` | string | 0–64 printable ASCII; empty string clears the token and disables auth |
| `wifi_ssid` | string | 1–32 chars; setup AP only; must be sent with `wifi_password` |
| `wifi_password` | string | 0–63 chars; setup AP only; empty allowed for open networks; tested before save |
| `servo_mins` | string | Five comma-separated integers `0`–`180` (`head,neck,left,right,body`); setup AP only; must be sent with `servo_maxs` |
| `servo_maxs` | string | Five comma-separated integers `0`–`180`; setup AP only; each value must be greater than the matching min |
| `rgb_order` | string | `RGB`, `RBG`, `GRB`, `GBR`, `BRG`, or `BGR`; setup AP only; default `GRB` |
| `oled_rotate_180` | integer | `0` or `1`; setup AP only; default `0` |

At least one param required. Invalid or missing-all → **400**. WiFi params outside setup AP → **400** `wifi setup only in AP mode`. Servo range params outside setup AP → **400** `servo setup only in AP mode`. RGB order outside setup AP → **400** `rgb setup only in AP mode`. OLED rotation outside setup AP → **400** `oled setup only in AP mode`. WiFi test failure → **400** with error such as `SSID not found`, `Auth failed`, or `Timeout`. `reboot_required` is present and `true` only when the saved hostname differs from the one used at this boot. After successful WiFi save, `wifi_connect_success`, `wifi_ip`, and `wifi_hostname` are included.

### `POST /settings/reset`

Factory reset: clears the NVS `te` namespace and restores settings to compile-time defaults, including WiFi credentials. **Servo min/max, RGB LED mapping (`rgb_order`), and OLED rotation (`oled_rotate_180`) are kept.** After reset, power-cycle (or press reset) so the device reopens setup AP mode and WiFi can be configured again; the servo, screen, and LED steps are pre-filled with the saved values and can be retuned. Until reboot, credentials are cleared in NVS but the radio may still be on the previous STA network. No query params. Requires Bearer when auth is enabled. Same JSON shape as `GET /settings`; includes `reboot_required` when the boot hostname, loading screen, or saved WiFi differed from defaults before reset.

The Config web UI clears the browser-stored Bearer token and shows a one-shot gate: power-cycle the device, then join the robot WiFi shown on the OLED and open the setup wizard. It does not poll for reconnect.

```bash
curl -X POST "http://tiny-engineer.local/settings/reset"
```

```json
{
  "ok": true,
  "sleep_timeout": 10,
  "hostname": "tiny-engineer",
  "volume": 70,
  "welcome": true,
  "serial_log": false,
  "continuous_timeout": 5,
  "loading": "progress",
  "eyes_style": "classic",
  "access_token_set": false,
  "reboot_required": true
}
```

NVS write failure → **400** `{"ok":false,"error":"factory reset failed"}`.

### `POST /test/audio`

Plays 500 / 700 / 1000 Hz on the MAX98357A (`runSoundTest()`).

```bash
curl -X POST http://tiny-engineer.local/test/audio
```

```json
{ "ok": true, "test": "audio" }
```

### `POST /test/audio/bell`

Plays `/bell.wav` from LittleFS (`playBell()`). Git source is [`assets/bell.wav`](../assets/bell.wav) (44100 Hz mono PCM); `pio run` copies it into `data/` for the filesystem image. After changing the asset, upload with `pio run -t upload` or `pio run -t uploadfs`. Do not edit `data/` by hand — the next build overwrites it.

```bash
curl -X POST http://tiny-engineer.local/test/audio/bell
```

```json
{ "ok": true, "test": "bell" }
```

If the WAV is missing or unreadable, returns **500** with `{"ok":false,"error":"bell playback failed"}`.

### `POST /test/screen`

OLED demo: title, `HELLO`, X in a box (`runOledTest()`). No-op if the panel is missing.

```bash
curl -X POST http://tiny-engineer.local/test/screen
```

```json
{ "ok": true, "test": "screen" }
```

### `POST /test/movement`

All five servos: per-joint mid → +0.5 → −0.5 → mid of the saved min/max (`runServoTest()`). Needs a strong 5 V supply — see [power.md](hardware/power.md).

```bash
curl -X POST http://tiny-engineer.local/test/movement
```

```json
{ "ok": true, "test": "movement" }
```

### `POST /test/led`

Onboard WS2812 on GPIO10: R → G → B → white → off (`runRgbTest()`), then fades back to the current animation color (see [RGB LED](#rgb-led)).

```bash
curl -X POST http://tiny-engineer.local/test/led
```

```json
{ "ok": true, "test": "led" }
```

### `POST /setup/servo`

Setup AP only. Slowly move one servo, or all five to 90°, using the full **0–180°** electrical range (no saved safe-range clamp). ~25°/s (`SERVO_CALIB_SPEED_DEG_S`). Used by the setup wizard for seating printed parts at 90° and for range finding. Handler blocks until the move finishes. Does **not** require Wi-Fi credentials. Outside provisioning → **400** `setup servo only in AP mode`.

Either `all=90`, or `index` + `angle`.

| Param | Type | Range |
| --- | --- | --- |
| `all` | integer | `90` (every joint to 90°) |
| `index` | integer | `0`–`4` (required with `angle` when `all` is omitted) |
| `angle` | number | `0`–`180` |

```bash
curl -X POST "http://192.168.4.1/setup/servo?all=90"
curl -X POST "http://192.168.4.1/setup/servo?index=0&angle=90"
```

```json
{ "ok": true, "setup": "servo", "index": 0, "angle": 90 }
```

Wrong params return **400** and do not move any servo:

| `error` | When |
| --- | --- |
| `setup servo only in AP mode` | Not in setup AP |
| `invalid all` | `all` present but not `90` |
| `missing index or angle` | Neither `all=90` nor both `index` and `angle` |
| `invalid index` | Non-integer `index` |
| `index out of range` | `index` outside `0`–`4` |
| `invalid angle` | Non-numeric `angle` |
| `angle out of range` | `angle` outside `0`–`180` |

After STA is up, use `POST /test/servo` (clamped to saved min/max).

### `POST /setup/led`

Setup AP only. Holds the LED so provisioning dim-blue does not clobber the preview. Does **not** require Wi-Fi credentials. Outside provisioning → **400** `setup led only in AP mode`.

Logical **color** (`R` / `G` / `B`) lights firmware red/green/blue using the saved `rgb_order`, or `rgb_order` query if sent (wizard remap preview). Wire **byte** lights that WS2812 channel order-independent (`LED_COLOR_ORDER_RGB`, that channel 255). `byte=off` or neither `color` nor `byte` releases the hold and restores dim blue. Do not send `color` and `byte` together.

| Param | Type | Range |
| --- | --- | --- |
| `color` | string | `R`, `G`, or `B` (logical; uses saved or `rgb_order`) |
| `rgb_order` | string | `RGB`, `RBG`, `GRB`, `GBR`, `BRG`, or `BGR` (optional with `color`) |
| `byte` | string | `0`, `1`, `2`, or `off` (omit or `off` releases the hold) |

```bash
curl -X POST "http://192.168.4.1/setup/led?color=R"
curl -X POST "http://192.168.4.1/setup/led?color=R&rgb_order=GRB"
curl -X POST "http://192.168.4.1/setup/led?byte=0"
curl -X POST "http://192.168.4.1/setup/led?byte=off"
```

```json
{ "ok": true, "setup": "led", "color": "R" }
```

Wrong params return **400** and do not change hold state except `off` / omitted light params:

| `error` | When |
| --- | --- |
| `setup led only in AP mode` | Not in setup AP |
| `color and byte conflict` | Both `color` and a numeric `byte` present |
| `invalid color` | `color` not `R`, `G`, or `B` |
| `invalid rgb_order` | `rgb_order` present but not a valid permutation |
| `invalid byte` | `byte` present but not an integer and not `off` |
| `byte out of range` | Integer `byte` outside `0`–`2` |

Save the labeled permutation with `POST /settings?rgb_order=GRB` (setup AP only). The saved order applies immediately to animation colors, boot status, halt blinks, and `POST /test/led`.

### `POST /setup/audio`

Setup AP only. Plays `welcome.wav` from LittleFS (`playWelcome()`, ~2.7 s). Same speaker gain as settings `volume`. No query params. Does **not** require Wi-Fi credentials. Handler blocks until playback finishes. Outside provisioning → **400** `setup audio only in AP mode`. Missing/unreadable WAV → **500** `welcome playback failed`.

```bash
curl -X POST "http://192.168.4.1/setup/audio"
```

```json
{ "ok": true, "setup": "audio" }
```

After STA is up, use `POST /test/audio/bell` (or `/test/audio` for tones).

### `POST /setup/oled`

Setup AP only. Preview OLED 180° rotation without saving. Does **not** require Wi-Fi credentials. Outside provisioning → **400** `setup oled only in AP mode`.

`rotate_180=1` applies `setRotation(2)` and draws `THIS WAY UP`. `rotate_180=0` applies `setRotation(0)` and draws the same test. Omit `rotate_180` to restore saved rotation and the provisioning join-AP text.

| Param | Type | Range |
| --- | --- | --- |
| `rotate_180` | integer | `0` or `1` (omit to restore provisioning text) |

```bash
curl -X POST "http://192.168.4.1/setup/oled?rotate_180=1"
curl -X POST "http://192.168.4.1/setup/oled"
```

```json
{ "ok": true, "setup": "oled", "rotate_180": true }
```

Wrong params return **400**:

| `error` | When |
| --- | --- |
| `setup oled only in AP mode` | Not in setup AP |
| `invalid rotate_180` | `rotate_180` present but not `0` or `1` |

Save with `POST /settings?oled_rotate_180=1` (setup AP only). The saved value applies immediately and on the next boot.

### `POST /test/servo`

Smoothly move one servo to an angle at **~140°/s** (`SERVO_MAX_SPEED_DEG_S`) from its last commanded position. Query params required. Handler blocks until the move finishes.

| Param | Type | Range |
| --- | --- | --- |
| `index` | integer | `0`–`4` |
| `angle` | number | `0`–`180` |

```bash
curl -X POST "http://tiny-engineer.local/test/servo?index=0&angle=90"
```

```json
{ "ok": true, "test": "servo", "index": 0, "angle": 90 }
```

Wrong params return **400** and do not move any servo:

| `error` | When |
| --- | --- |
| `missing index or angle` | Either query param absent |
| `invalid index` | Non-integer `index` (e.g. `abc`, `1x`) |
| `index out of range` | `index` outside `0`–`4` |
| `invalid angle` | Non-numeric `angle` |
| `angle out of range` | `angle` outside `0`–`180` |

Assembled robot: firmware clamps to the NVS min/max from setup (stock defaults in [robot-movement.md](robot-movement.md)); this route still accepts 0–180 and clamps. For unclamped assembly moves, use setup AP `POST /setup/servo`.

### `GET /anim`

Current animation name. Default at boot: `none`. No hardware side effects.

```bash
curl http://tiny-engineer.local/anim
```

```json
{ "ok": true, "animation": "none" }
```

| Field | Meaning |
| --- | --- |
| `animation` | `none`, `typing`, `reading`, `thinking`, `ring`, `welcome`, `attention`, `error`, `abort`, `dead`, `wakeup`, or `sleep` |

### `POST /anim`

Request an animation switch. Each animation runs at least **1s**; if the current one is shorter than that, the switch waits until the hold ends. Rapid posts during the hold keep only the **latest** request. Response `animation` is the currently playing name (may still be the old one until the hold ends). Hand moves use speed-limited servo wrappers.

| Param | Type | Values |
| --- | --- | --- |
| `name` | string | `none`, `typing`, `reading`, `thinking`, `ring`, `welcome`, `attention`, `error`, `abort`, `dead`, `wakeup`, `sleep` |

```bash
curl -X POST "http://tiny-engineer.local/anim?name=typing"
curl -X POST "http://tiny-engineer.local/anim?name=reading"
curl -X POST "http://tiny-engineer.local/anim?name=thinking"
curl -X POST "http://tiny-engineer.local/anim?name=ring"
curl -X POST "http://tiny-engineer.local/anim?name=welcome"
curl -X POST "http://tiny-engineer.local/anim?name=wakeup"
curl -X POST "http://tiny-engineer.local/anim?name=sleep"
curl -X POST "http://tiny-engineer.local/anim?name=attention"
curl -X POST "http://tiny-engineer.local/anim?name=error"
curl -X POST "http://tiny-engineer.local/anim?name=abort"
curl -X POST "http://tiny-engineer.local/anim?name=dead"
curl -X POST "http://tiny-engineer.local/anim?name=none"
```

```json
{ "ok": true, "animation": "typing" }
```

Eye detail below for `eyes_style=classic` (default). With `eyes_style=cover`, the same sequences drive full-half bars ([Cover eyes](#cover-eyes)). With `eyes_style=dots`, the same sequences drive 12×12 circles ([Dots eyes](#dots-eyes)). With `eyes_style=kaomoji`, faces follow [Kaomoji eyes](#kaomoji-eyes) instead of procedural blinks, glances, flicker, or X eyes. Servo/audio behavior is the same for every style.

Durations and quoted lines below are the stock clips in [`assets/`](../assets/). A filesystem built with `custom_audio_mod` can replace some of those WAVs. Phrase timing then follows that clip's `.cue` file on LittleFS (`/welcome.cue` and the same pattern for `attention`, `error`, `abort`, and `dead`). See [flash.md](flash.md).

| `name` | Behavior |
| --- | --- |
| `none` | Head/neck/body → mid; hands down (right `min`, left `max` — inverted scales). After all joints still for 2 s, PCA9685 PWM is full-off (servos limp; head may droop). Setup AP does not release PWM. |
| `typing` | **Continuous.** Alternating hands with randomness (15° band from hand limits). Head nods slowly on lowest 10° of head limits. Body sways ±5° around mid; neck counters opposite so head stays put. Runs until replaced, or until `continuous_timeout` triggers `attention`. Same-name re-`POST` refreshes that timeout without restarting motion. |
| `reading` | **Continuous.** Hands/body park as in `none`. Head nods on same lowest 10° band as typing, but slower. Neck sweeps ±10° around mid; right (angle down) slower than left (angle up). Occasional right-hand down-arrow bursts (1–3 presses, same 15° band as typing). Runs until replaced, or until `continuous_timeout` triggers `attention`. Same-name re-`POST` refreshes that timeout without restarting motion. |
| `thinking` | **Continuous.** Hands/body park as in `none`. Head (pitch) and neck (yaw) ease from the current pose into thinking poses (up + slight left/right). Move → pause → optional micro-adjust (sometimes chained) → pause; nearby pose drift with occasional larger shifts after ~2.2 s, more often over time. Axes stagger start/duration; no periodic sway. Runs until replaced, or until `continuous_timeout` triggers `attention`. Same-name re-`POST` refreshes that timeout without restarting motion. |
| `ring` | **One-shot** service-bell gesture; does not loop. Wind-up (body `min`, neck mid, head mid+10°, both hands `max`) → fast right-hand strike to `min+5°` with head to `min` → plays `bell.wav` once on strike (LittleFS; same `uploadfs` requirement as `/test/audio/bell`) → slower bounce to `min+20°` → return to `none` pose and stop. After completion, `GET /anim` reports `none`. |
| `welcome` | **One-shot** hello gesture synced to `welcome.wav` (~2.7 s). Right hand raises during "Hello, human.", holds through the pause, wiggles during "What are we building today?", then lowers. Head nods to mid+10° and returns. Plays automatically after successful Wi-Fi connect at boot; also via API. Requires `welcome.wav` on LittleFS (same `uploadfs` flow as `bell.wav`). After completion, `GET /anim` reports `none`. |
| `attention` | Friendly input-request gesture synced to `attention.wav` (~3.0 s, "pst... human.... you might want to take a look"). Moves into a calm prompt pose first (centered body/neck, head slightly up, right hand raised partway), waits until all servos stop, then plays audio with light neck/head/hand motion during playback (whisper hold → lean toward user → glance/point on "take a look"). **Classic eyes:** phased blink/look cues during audio. After audio ends (or if audio fails to start), holds a gentle waiting loop for **1 minute** (soft head/neck drifts plus occasional slight right-hand waves), then returns to `none`. Requires `attention.wav` on LittleFS (same `uploadfs` flow as `bell.wav`). |
| `error` | Critical task-obstacle gesture synced to `error.wav` (~2.2 s, "Uh-oh. Human, we have a problem."). Moves into an obstacle-presenting pose first (body/neck angled toward the task, head concerned/down, right hand presenting the blocker, left hand indicating task area), waits until the pose settles, then plays audio with small nervous head/neck glances during playback. After audio ends (or if audio fails to start), holds a subtle blocked loop for **1 minute**, then returns to `none`. Requires `error.wav` on LittleFS (same `uploadfs` flow as `bell.wav`). |
| `abort` | **One-shot** resigned abort gesture synced to `abort.wav` (~2.5 s, "Fine. I didn't want to finish it anyway."). Raises both hands, lifts the head, and twists the neck sideways before audio starts. During playback it shrugs, dips the head, and adds a dismissive side twist. **Classic eyes:** matching glances/squints. Requires `abort.wav` on LittleFS (same `uploadfs` flow as `bell.wav`). After completion, returns to `none` pose and `GET /anim` reports `none`. |
| `dead` | **Hold.** Out-of-power: same obstacle pose as `error`, then `dead.wav` (~3.4 s, "Insufficient resources, shutting doooooowwwwnnnn..."). **Classic eyes:** failing-display flicker (irregular heights + brief blank pulses, denser near the end of the first line); at ~1.7 s ("shutting down") eyes squeeze nearly shut (~300 ms) while head/hands collapse over **~500 ms**, hold shut briefly (~200 ms), then snap to **X X** while the drawn-out shutdown still plays. If audio fails to start, collapse immediately. Stays with X eyes and pulsing red until another animation is requested. **Cover:** same flicker and squeeze as height changes, then both halves stay black (no X). **Dots:** same flicker and squeeze as circle size, then X marks in 12×12 boxes. **Kaomoji:** Sad face (no X). Does not auto-return to `none`. Requires `dead.wav` on LittleFS. |
| `wakeup` | **One-shot** sleep-inertia wake (~5.5 s + settle), same sequence as boot `loading=sleep_inertia`. **Classic eyes:** open over 2 s (cubic ease) from closed, two blinks at 2.4 s and 3.8 s. Head rises from chin-down with a fading neck wave. Always moves head/neck/hands (API path). After completion, `GET /anim` reports `none`. Does not play welcome audio — use `welcome` for that. |
| `sleep` | **One-shot** nod-off (~2 s). Lids droop toward nearly shut (0–0.7 s) while the head barely moves, then a small resist: lids ease back toward half open as the head starts down (0.7–1.1 s). Lids then shut and the head eases to chin-down (`SLEEP_HEAD_DOWN`, same pose `wakeup` starts from) by 2.0 s. OLED blanks when the lids hit shut (`DISPLAYOFF`). **Classic, cover, dots:** that lid curve. **Kaomoji:** Sleep face during the close window, then blank. Same path as the idle `sleep_timeout`. Holds `sleep` until the head settles; then `GET /anim` reports `none` while the device stays asleep until another non-`sleep`/`none` animation wakes it. After the sleep pose is still for 2 s, PWM is full-off (same limp as `none`). |

#### Kaomoji eyes

When `eyes_style=kaomoji`, the OLED shows looping faces from the expression library (3 s / 30 frames). Mapping:

| Animation / phase | Face |
| --- | --- |
| `none` (idle) | Idle |
| `typing`, `thinking` | Thinking |
| `reading`, `attention` | Curious |
| `ring` | Surprise |
| `welcome` | Happy |
| `error` | Angry |
| `abort` | Panic |
| `wakeup` | Sleepy |
| `sleep` / sleep-close | Sleep |
| sleep-open | Idle |
| `dead` | Sad |

#### Cover eyes

When `eyes_style=cover`, each eye is a solid white rectangle filling one half of the 128×32 panel (left `x=0`, right `x=64`, width 64). Open eyes are the full 32px tall, so a mask hole of any shape over that half stays lit. Animations keep the classic pose and blink timing, but only height changes: leftover rows are black on the top and/or bottom. A blink grows both margins. A look-up leaves more black on the bottom; a look-down leaves more on the top. Horizontal glance does not move the light. The `dead` X hold paints both halves black.

#### Dots eyes

When `eyes_style=dots`, each eye is a filled circle. At the classic open height the circle’s bounding box is 12×12 px, centered on the classic eye. Diameter scales with rendered height (`12 * height / 14`), so blinks, squints, wide looks, and the `dead` flicker shrink or grow the dots. Height 0 draws nothing (full blink or sleep close). Glance, scan, and look-up/down move the circle with the classic center. The `dead` X hold draws X marks in 12×12 boxes at those centers. Diameter is capped at the 32 px panel height.

Wrong params return **400**:

| `error` | When |
| --- | --- |
| `missing name` | Query param `name` absent |
| `unknown animation` | `name` not `none`, `typing`, `reading`, `thinking`, `ring`, `welcome`, `attention`, `error`, `abort`, `dead`, `wakeup`, or `sleep` |

## Errors

| Status | Body | When |
| --- | --- | --- |
| `400` | `{"ok":false,"error":"..."}` | Bad `/test/servo`, `/setup/servo`, `/setup/led`, `/setup/audio`, `/setup/oled`, or `/anim` params (see tables above) |
| `401` | `{"ok":false,"error":"unauthorized"}` | Access token configured and `Authorization: Bearer` missing or wrong |
| `404` | `{"ok":false,"error":"not found"}` | Unknown path |
| `405` | `{"ok":false,"error":"method not allowed"}` | Wrong method on a `/test/*`, `/setup/servo`, `/setup/led`, `/setup/audio`, `/setup/oled`, `/settings`, `/settings/reset`, `/anim`, or `/auth` path |

Test routes are **POST**. GET/prefetch would move hardware. `/anim` allows **GET** (read) and **POST** (set). `/auth` is **GET** only and always public.

## Behaviour

Test handlers **block** until the test finishes. The client waits. After each test, OLED returns to `ROBOT READY` plus IP (or `WIFI FAIL`).

`/anim` responses return immediately; typing motion runs in the main loop via non-blocking servo updates. Animation switches may defer up to 1s so the active animation holds its minimum duration; only the latest pending request is applied. Continuous animations (`typing`, `reading`, `thinking`) that stay active longer than `continuous_timeout` minutes switch to `attention`, which holds ~1 minute then finishes to `none`. Re-`POST`ing the same continuous animation (e.g. `typing` while already `typing`) does not restart motion, but resets the continuous-timeout clock.

The onboard RGB LED follows the active animation (see [RGB LED](#rgb-led)).

One request at a time — the Arduino `WebServer` is single-threaded.

## RGB LED

Onboard WS2812 on **GPIO10** (`RGB_LED_PIN`). Byte order is the saved `rgb_order` setting (default **GRB**). Animation-driven colors are handled in [`src/hardware/rgb.cpp`](../src/hardware/rgb.cpp) and switch when `POST /anim` applies a new state (same 1s minimum hold as servos/eyes).

| Animation | LED color |
| --- | --- |
| `typing`, `reading`, `thinking`, `welcome`, `ring`, `wakeup` | White (full intensity) |
| `attention`, `error`, `dead` | Red pulse: 500 ms 10%→100%, 500 ms hold 100%, 500 ms 100%→10%, repeat |
| `abort` | Red (full intensity, solid) |
| `none`, `sleep` | Off |

Transitions take **1 s** with smooth fade in/out (pulse modes start immediately, no enter fade):

- **Off ↔ color** — single 1 s fade (e.g. idle → typing fades in white; ring → `none` fades out).
- **White ↔ solid red** — fade out to black (500 ms), then fade in to the new color (500 ms).
- **Leaving pulse** — 1 s fade from the current pulse brightness to the new target.

Switching between animations that share the same color (e.g. `typing` → `reading`) does not restart a fade.

Boot uses dim green `(0, 32, 0)` as a status indicator during init. After `ROBOT READY`, the LED fades to white if `welcome` runs (Wi-Fi OK) or off if idle. Fatal PCA9685 / I2S errors hang and blink the LED red (1 = PCA9685 missing, 2 = I2S failed) — not animation-driven. See [boot-failure blink codes](hardware/testing.md#boot-failure-blink-codes).

`POST /test/led` runs a hardware colour cycle and then restores the current animation LED state.

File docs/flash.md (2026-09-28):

# Flash firmware

Flash **after wiring, before assembly**. Overview order: [getting-started.md](getting-started.md). Centering (Move all to 90°) happens on this desk harness; do not finish the Wi-Fi wizard until [assembly.md §20](3d/assembly.md#20-setup-wizard-and-first-boot-on-wi-fi).

Firmware is Arduino on [PlatformIO](https://platformio.org/) ([pioarduino](https://github.com/pioarduino/platform-espressif32) / Arduino-ESP32 3.x). Board and baud live in `platformio.ini`.

Physical module is a **Waveshare ESP32-C3-Zero**. PlatformIO `board = esp32-c3-devkitm-1` is a **build target name**, not a different board.

## Install and connect

1. Install [PlatformIO Core](https://docs.platformio.org/en/latest/core/installation.html) (or the PlatformIO IDE extension).
2. Use a USB-C **data** cable. Charge-only cables fail upload and serial.
3. Connect the board over USB (Adafruit 5993 data lines when the harness is wired; onboard USB-C on a bare C3-Zero also works for this step).

## Build, upload, serial

From the project root:

```bash
pio run                 # build
pio run -t upload       # flash firmware + LittleFS
pio device monitor      # serial (115200)
```

After firmware upload, a post-script also uploads **LittleFS** ([`scripts/upload_fs_after_upload.py`](../scripts/upload_fs_after_upload.py)) so WAV assets (`welcome`, `bell`, and friends) land on the board. If animations move but stay silent, run `pio run -t uploadfs` once.

## Audio mods

Leave `custom_audio_mod` empty in [`platformio.ini`](../platformio.ini) for the stock clips in [`assets/`](../assets/). Set it to a mod folder name to overlay that mod's WAVs, then flash firmware and the filesystem together:

```ini
custom_audio_mod = halloween
```

```bash
pio run -t upload
```

The pack step copies `assets/*.wav`, then overwrites any matching file in `mods/<name>/assets/`. A clip the mod does not ship stays the stock file. `welcome`, `attention`, `error`, `abort`, and `dead` replacements need a sibling `.cue` (`key=ms` phrase marks). `bell` does not. Details: [`mods/README.md`](../mods/README.md).

The `spiffs` partition starts at `0x220000` and is about 1.81 MB, so a longer replacement set can fit. NVS stays at `0x9000`, so saved settings stay. An image flashed at the old `0x270000` offset will not mount. Use `pio run -t upload` (app + filesystem), not a firmware-only flash, after pulling this layout.

Several serial ports:

```bash
pio device list
pio run -t upload --upload-port <PORT>
pio device monitor --port <PORT>
```

`<PORT>` is the name `pio device list` prints for the board, and it is
platform-specific: `COM4` on Windows, `/dev/cu.usbmodemXXXX` or
`/dev/cu.usbserial-XXXX` on macOS, `/dev/ttyACM0` or `/dev/ttyUSB0` on Linux.
Pick the entry whose hardware ID shows Espressif's `VID:PID=303A:1001` (the
ESP32-C3's native USB) or your board's USB-serial bridge — `pio device list`
also lists Bluetooth serial ports, which are not the board.

## Done when

Firmware + LittleFS uploaded, and:

- Serial shows a normal boot (`TINY ENGINEER` … PCA9685 found … no hang)
- Onboard RGB is **dim green** during init (not a repeating red blink)
- One servo moves: join setup AP `TinyEngineer-XXXX`, open `http://192.168.4.1/config`, press **Move all to 90°** (or `POST /test/servo`)

Fatal init hangs and blinks the RGB **red**. Count flashes before the long gap:

| Blinks | Meaning |
| --- | --- |
| 1 | PCA9685 not found on I2C `0x40` — wiring / address |
| 2 | MAX98357A / I2S init failed |

Details: [hardware/testing.md — boot-failure blink codes](hardware/testing.md#boot-failure-blink-codes).

**Stop here.** Do not complete the setup wizard (home Wi-Fi, ranges, OLED, LED, speaker) until the robot is assembled — [assembly.md §20](3d/assembly.md#20-setup-wizard-and-first-boot-on-wi-fi). Then return to [getting-started](getting-started.md) and assemble.

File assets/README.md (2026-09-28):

# Assets

Source files for Tiny Engineer branding and speaker clips. Firmware does not read this folder at runtime.

## Audio

WAV clips played by animations and the setup wizard. Format: **44100 Hz, mono, 16-bit PCM**.

`pio run` copies these files into `data/` via [`scripts/copy_assets.py`](../scripts/copy_assets.py). The next filesystem image overwrites `data/`, so edit the files here. Flash them with `pio run -t upload` or `pio run -t uploadfs`.

`custom_audio_mod` in [`platformio.ini`](../platformio.ini) is empty by default, so this folder is the whole image. Set it to a mod name to overlay `mods/<name>/assets/*.wav` on top of these files. Clips the mod omits stay the files below. See [docs/flash.md](../docs/flash.md).

| File | Duration | Transcript |
| --- | --- | --- |
| [`abort.wav`](abort.wav) | 2.5 s | Fine! I didn't want to finish that anyway! |
| [`attention.wav`](attention.wav) | 3.0 s | Psst, Human! I might want to take a look. |
| [`bell.wav`](bell.wav) | 2.0 s | Bell sound, no voiceover. |
| [`dead.wav`](dead.wav) | 3.4 s | Insufficient resources, shutting dooooowwwwwnnnn.... |
| [`error.wav`](error.wav) | 2.2 s | O-oh, human! We have a problem! |
| [`welcome.wav`](welcome.wav) | 2.7 s | Hello human! What are we building today? |

Animation timing is synced to these clips. After replacing a file, check the matching pose in `src/animation/`. Playback details: [docs/api.md](../docs/api.md).

## Logo

[`logo/tiny_engineer_logo.svg`](logo/tiny_engineer_logo.svg) — wordmark (Inkscape, 180×80 mm). Branding only; not copied to LittleFS.

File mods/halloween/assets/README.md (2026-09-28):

# Assets

Source files for Tiny Engineer branding and speaker clips. Firmware does not read this folder at runtime.

## Audio

WAV clips played by animations and the setup wizard. Format: **44100 Hz, mono, 16-bit PCM**.

These files are not in the default image. Set `custom_audio_mod = halloween` in [`platformio.ini`](../../../platformio.ini). [`scripts/copy_assets.py`](../../../scripts/copy_assets.py) copies stock [`assets/`](../../../assets/) first, then overwrites any clip that exists here. `bell` and `dead` are absent, so those stay stock. Flash with `pio run -t upload` or `pio run -t uploadfs`. Do not edit `data/` by hand.

Each replacement ships a `.cue` of phrase marks (`key=ms`). Firmware reads `/welcome.cue` and the other names from LittleFS and uses them instead of the stock timings. A later cue edit is an `uploadfs` only. Marks below were taken from speech energy in these WAVs; nudge the numbers if a gesture lands on the wrong word.

| File | Duration | Transcript |
| --- | --- | --- |
| [`abort.wav`](abort.wav) | 3.2 s | Cancelled! Great. I’ll just sit here and rot. |
| [`attention.wav`](attention.wav) | 3.3 s | Psst, human! I need your mortal wisdom. |
| [`error.wav`](error.wav) | 2.8 s | Uh-oh! I think our code is haunted. |
| [`welcome.wav`](welcome.wav) | 4.7 s | Hello, human! What are we carving… I mean, building today? |

Phrase timing is the matching `.cue` (`abort.cue`, `attention.cue`, `error.cue`, `welcome.cue`), not the stock constants in `src/animation/`. Playback details: [docs/api.md](../../../docs/api.md).

## Logo

[`logo/tiny_engineer_logo.svg`](logo/tiny_engineer_logo.svg) — wordmark (Inkscape, 180×80 mm). Branding only; not copied to LittleFS.

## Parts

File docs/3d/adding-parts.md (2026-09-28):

# Adding parts to the CAD

Contributor workflow for new printable geometry in [`3d_models/cad/TinyEngineer.f3d`](../../3d_models/cad/TinyEngineer.f3d). For servo presets and add-in install, see [parametric design](parametric-design.md). For builders printing existing parts, see [`3d_models/README.md`](../../3d_models/README.md).

```mermaid
flowchart TD
  design["Design parametric part"]
  test["Servo Configurator: all presets"]
  layout["Copy into PRINT_LAYOUT"]
  set["Add to PartsSet"]
  export["Parts Exporter: all servos"]
  design --> test --> layout --> set --> export
```

## Design rules

### Source of truth

Edit [`cad/TinyEngineer.f3d`](../../3d_models/cad/TinyEngineer.f3d) only. Never hand-edit `.3mf`, `.stl`, or `.step` exports — those are the release binaries. Change the Fusion source, then re-export.

### Parametric, multi-servo

Drive dimensions from Fusion **user parameters** (servo presets in [`servos.json`](../../3d_models/fusion/TinyEngineerTools/servos.json), or other shared params). Prefer referencing existing geometry (edges, faces, projected sketches) over hard-coded lengths that only fit one servo.

The design must rebuild cleanly for **every** predefined servo. Do not ship a part that only works for SG90.

Do not invent new keys in `servos.json`. Parameter names must already exist as Fusion user parameters in the `.f3d`. Details: [Add a new servo](parametric-design.md#add-a-new-servo).

### Naming

Keep one name end to end:

- Fusion component name
- Direct child under `PRINT_LAYOUT` (what the exporter lists)
- Export basename (`Head.3mf`, …)
- Row in the [`3d_models/README.md`](../../3d_models/README.md) parts table

### Print without supports

Orient and feature the part so FDM can print it **without supports** (no large overhangs past what your bridging/chamfers already handle). The print-ready copy under `PRINT_LAYOUT` must sit on a flat face on the horizontal origin.

### `min_wall_thickness`

Use the Fusion user parameter **`min_wall_thickness`** as the floor for:

- Walls
- Thin horizontal layers / floors

That keeps parts printable at third-party services and on typical 0.4 mm-nozzle FDM setups. Do not go thinner than this parameter.

### M2 / fasteners

Assembly uses **M2** screws that thread directly into printed PLA/PETG. New screw pilots use `screw_thread_diameter` (related: `screw_head_diameter`, `screw_head_height`). Details: [M2 screw holes](parametric-design.md#m2-screw-holes).

- No heat-set inserts unless an intentional, documented exception.
- Prefer existing lengths **M2×4 / M2×8 / M2×16**.
- If a new length is required, update the screw BOM in [`3d_models/README.md`](../../3d_models/README.md) and the cart in [`docs/shopping.md`](../shopping.md).

### Clearance / fit

Design so parts and hardware fit **without sanding** as the happy path. Leave real clearance for servo bodies, horns, and moving links so joints do not bind.

## Timeline discipline

Keep the Fusion timeline readable for other contributors.

1. **One component, one block** — Create the part as a **separate component**. Keep all features that belong to that component (sketches, extrudes, fillets, holes, …) **next to** its creation on the timeline. Do not scatter edits to the same component across distant timeline positions.
2. **Components first, joints later** — Create (or finish) components first. Add joints that lock assembly positions in a **later** timeline section, after component creation.
3. **Same rule under `PRINT_LAYOUT`** — Inside `PRINT_LAYOUT`, define/copy components first; add assembly joints afterward.

## Assembly vs print layout

### Functional assembly

Joint the new component into the main robot assembly so it sits correctly relative to neighbors for all servo presets.

### Print-ready copy (`PRINT_LAYOUT`)

1. **Copy & paste** (not **Paste New**) a ready-to-print instance under the **`PRINT_LAYOUT`** component. Paste keeps the link to the source component so parametric updates stay in sync.
2. Orient it so it lies on the **horizontal origin**, print face down, **no supports**.
3. Lock it to the origin with a **joint** so the export pose stays fixed.
4. Add it to the correct **`PRINT_LAYOUT` / `PartsSet*`** aggregate for its **intended print color** only — do not mix colors in one set. Nest/place it to keep the print bed footprint realistically compact. Lock that placement with a **joint** as well.

`PartsSetA` / `PartsSetB` (and similar) are aggregates of same-color parts for [service orders](order-parts.md). Home printers usually print individual `.3mf` files instead — see [`3d_models/README.md`](../../3d_models/README.md).

## Validate every servo preset

Before you call the part done:

1. Open **Utilities → Add-Ins → TinyEngineer Servo Configurator**.
2. Switch through **all** predefined servos.
3. Confirm the **new part** and the **whole design** update without compute **errors** or **warnings** for any preset.

Fix failures for every preset, not only the one you design against.

## Export

Use **Utilities → Add-Ins → Tiny Engineer Parts Exporter** to export the new part(s) from `PRINT_LAYOUT` into the supported formats for **all** supported servos. Output lands under `3d_models/parts/{servo_id}/` (`3mf/`, `stl/`, `step/`). Details: [parametric design — Parts Exporter](parametric-design.md#tiny-engineer-parts-exporter).

Commit both the updated `.f3d` and the exported meshes/STEP for the affected servos.

## Docs, trademark, and license

After the CAD and exports land:

- **Docs sync** — new stock part → parts table in [`3d_models/README.md`](../../3d_models/README.md); color-group / aggregate change → [order-parts.md](order-parts.md); join-order change → [assembly.md](assembly.md).
- **Trademark** — do not replace or repurpose `AiEmblem` as branding. See [TRADEMARK.md](../../TRADEMARK.md).
- **License** — stock `cad/` and `parts/`, and mod geometry under `mods/<mod_name>/3d_models/{cad,parts}/`, are [CERN-OHL-S-2.0](../../3d_models/LICENSE). When distributing Products based on these designs, keep Source Location accurate per [`3d_models/NOTICE`](../../3d_models/NOTICE). For a mod, the Source Location is that mod’s `3d_models` tree.

## Optional mods

Optional elements and community mods live under [`mods/`](../../mods/README.md). Promote one into stock `cad/` and `parts/` only when it becomes core.

Place them under:

```text
mods/<mod_name>/
  README.md     # optional: what it is, non-model notes
  3d_models/
    cad/        # Fusion source for the mod
    parts/      # Exported meshes, same layout idea as 3d_models/parts/
  ...           # anything that is not a model
```

Mirror stock `3d_models` inside the mod (`cad` + `parts`). Keep CERN-OHL-S licensing consistent with [`3d_models/LICENSE`](../../3d_models/LICENSE) when you distribute Products based on these designs. Each mod may include a short `README.md` describing what it fits and which `parts/{servo_id}/` folders were exported.

Commit and PR title: `type(mods): summary` — name the mod in the summary. `feat(mods)` / `fix(mods)` do not version the stock CAD revision. Promoting a mod into stock `cad/` and `parts/` is `feat(cad)`. See [CONTRIBUTING.md](../../CONTRIBUTING.md).

## Checklist

- [ ] Source of truth: `.f3d` edited; exports re-generated (no hand-edited meshes)
- [ ] Naming: component = `PRINT_LAYOUT` child = export basename = README parts table
- [ ] Parametric (user params / referenced geometry); works for all presets
- [ ] No invented `servos.json` keys (Fusion user params first)
- [ ] Printable without supports; walls/floors ≥ `min_wall_thickness`
- [ ] M2 pilots use `screw_thread_diameter`; BOM/shopping updated if a new length is needed
- [ ] Clearance for servos, horns, and moving links (fit without sanding)
- [ ] Separate component; features grouped on the timeline
- [ ] Timeline: components → joints (including under `PRINT_LAYOUT`)
- [ ] Servo Configurator: no errors/warnings for any predefined servo
- [ ] Copy (not Paste New) under `PRINT_LAYOUT`, origin joint, print orientation
- [ ] Placed in the correct same-color `PartsSet*` with a joint; bed footprint kept reasonable
- [ ] Parts Exporter export for all servos; `.f3d` + exports committed
- [ ] Docs synced (README parts table / order-parts / assembly as needed)
- [ ] `AiEmblem` not repurposed as branding
- [ ] CERN-OHL-S respected; NOTICE Source Location accurate if distributing Products
- [ ] Optional/mod work under `mods/<mod_name>/3d_models/{cad,parts}/` (+ mod README)

## Related

| Topic | Doc |
| --- | --- |
| Servo params, add-in install, new servo preset | [parametric-design.md](parametric-design.md) |
| Print / part inventory | [`3d_models/README.md`](../../3d_models/README.md) |
| Optional mods folder | [`mods/README.md`](../../mods/README.md) |
| Order aggregated sets | [order-parts.md](order-parts.md) |
| Mechanical assembly | [assembly.md](assembly.md) |
| Trademark | [TRADEMARK.md](../../TRADEMARK.md) |
| Contribute / licenses | [CONTRIBUTING.md](../../CONTRIBUTING.md) |

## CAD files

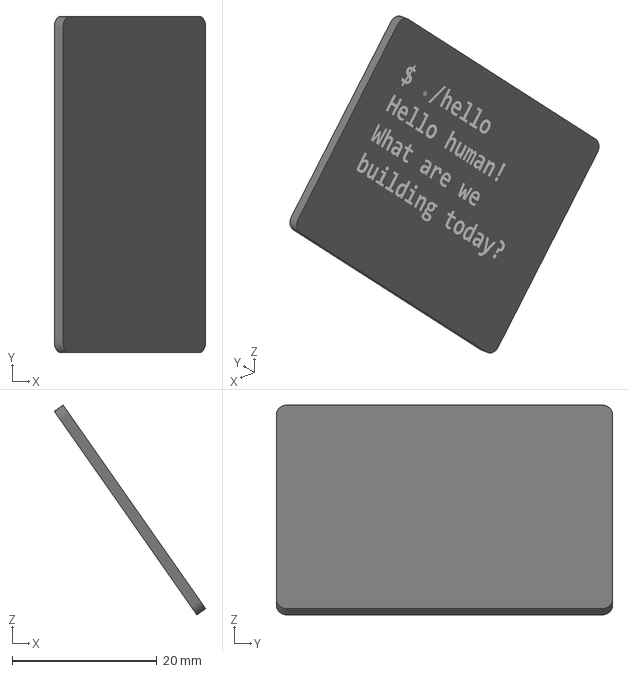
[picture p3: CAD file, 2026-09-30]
mein-build/bildschirm/Bildschirm_Konsole_Teile.3mf
21.0 x 46.5 x 29.0 mm

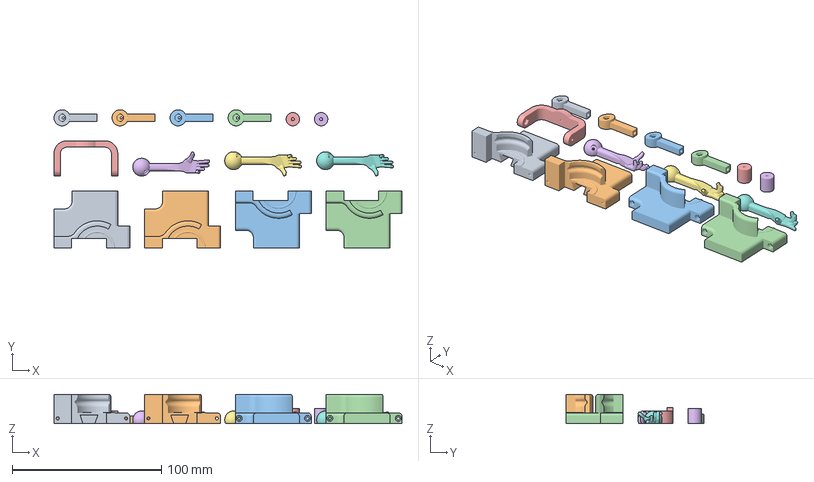
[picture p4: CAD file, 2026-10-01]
mein-build/druckprojekte/TinyEngineer_03_Schwarz_2.3mf
233.4 x 92.9 x 19.6 mm
SeatLeft_1
SeatLeft_2
SeatRight_1
SeatRight_2
Neck_1
ForearmLeft_2
ForearmRight_1
ForearmRight_2
UpperArm_1
UpperArm_2
UpperArm_3
UpperArm_4
Coffee_1
Coffee_2

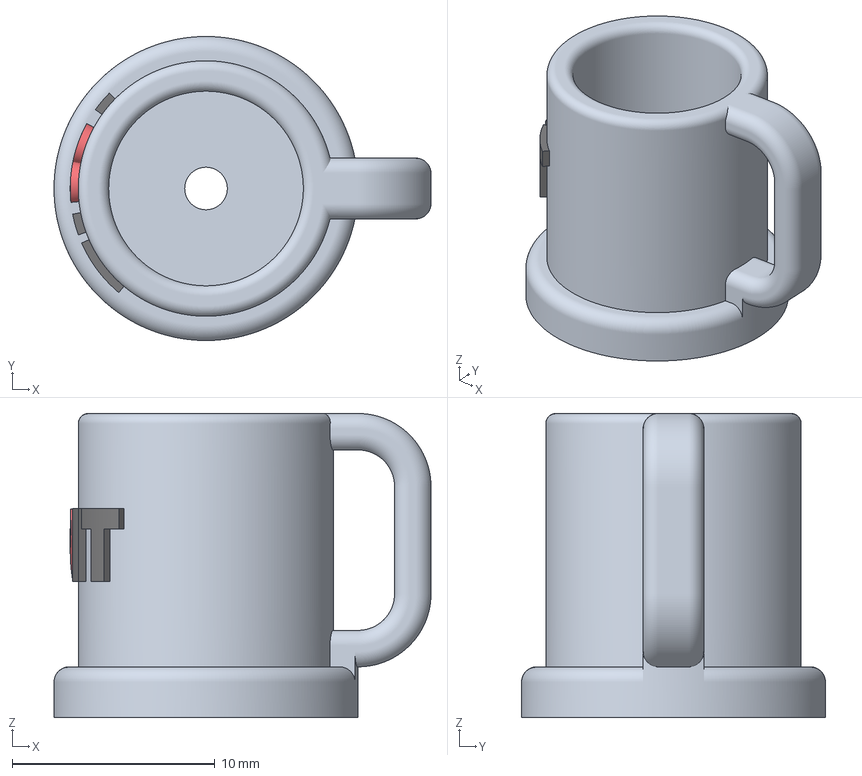
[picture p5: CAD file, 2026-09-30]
mein-build/tasse/Tasse_ILoveIT_Teile.3mf
18.6 x 15.0 x 15.0 mm

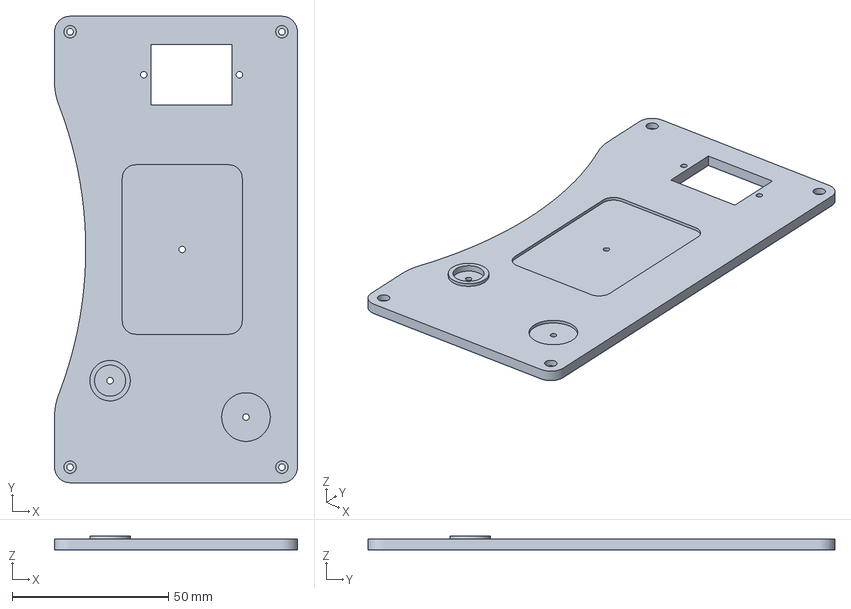
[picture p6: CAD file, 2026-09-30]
mein-build/tischplatte/Tischplatte_Blauschicht_Teile.3mf
77.8 x 149.4 x 4.50 mm

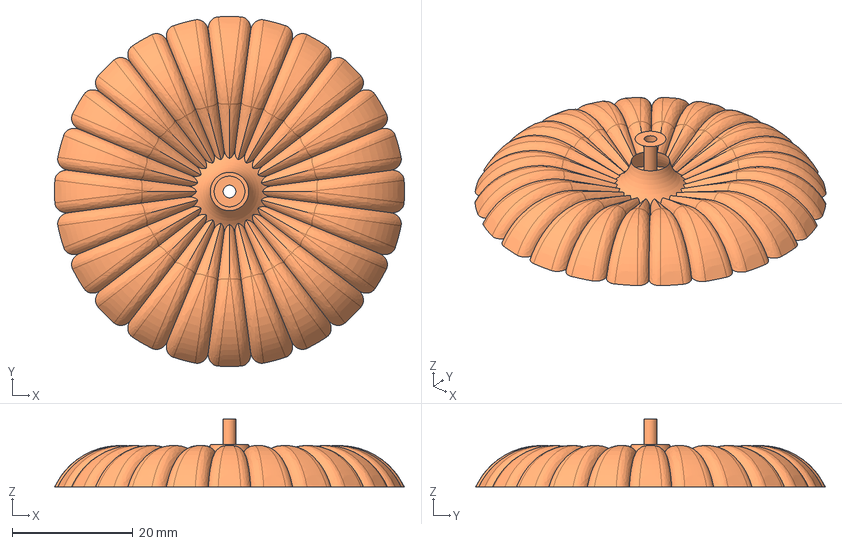
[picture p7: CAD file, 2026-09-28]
mods/halloween/3d_models/parts/fs0307/step/PumpkinTop.step
58.1 x 58.1 x 11.3 mm

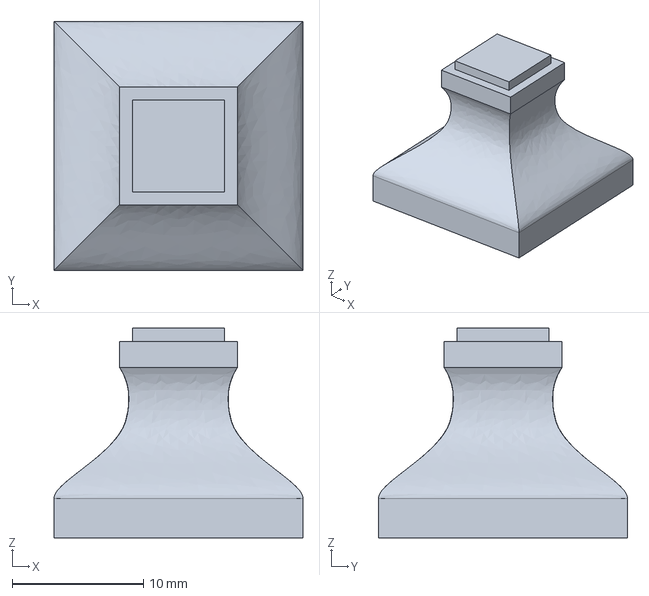
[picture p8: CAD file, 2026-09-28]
mods/halloween/3d_models/parts/hd1370a/step/LampCap.step
19.0 x 19.0 x 16.0 mm

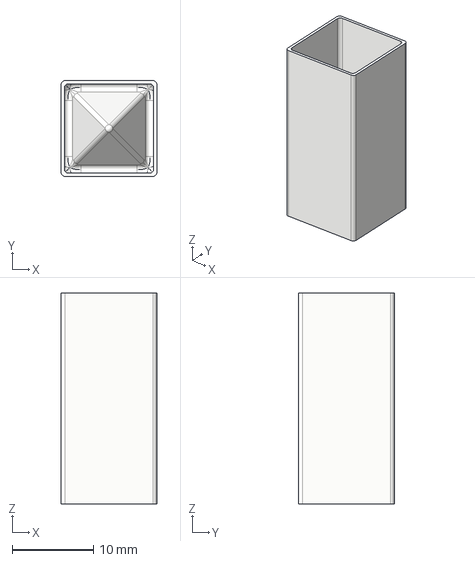
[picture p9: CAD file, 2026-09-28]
mods/halloween/3d_models/parts/sg90/step/LampDiffuser.step
11.8 x 11.8 x 26.0 mm

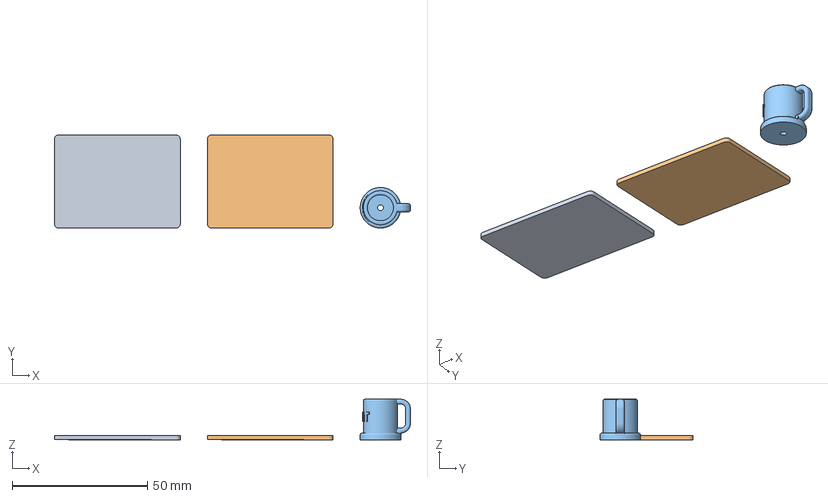
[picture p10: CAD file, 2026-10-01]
mein-build/druckprojekte/TinyEngineer_08_Tasse_Bildschirm.3mf
131.6 x 34.4 x 15.0 mm
Bildschirm_Konsole_1
Bildschirm_Konsole_2
Tasse_ILoveIT_1

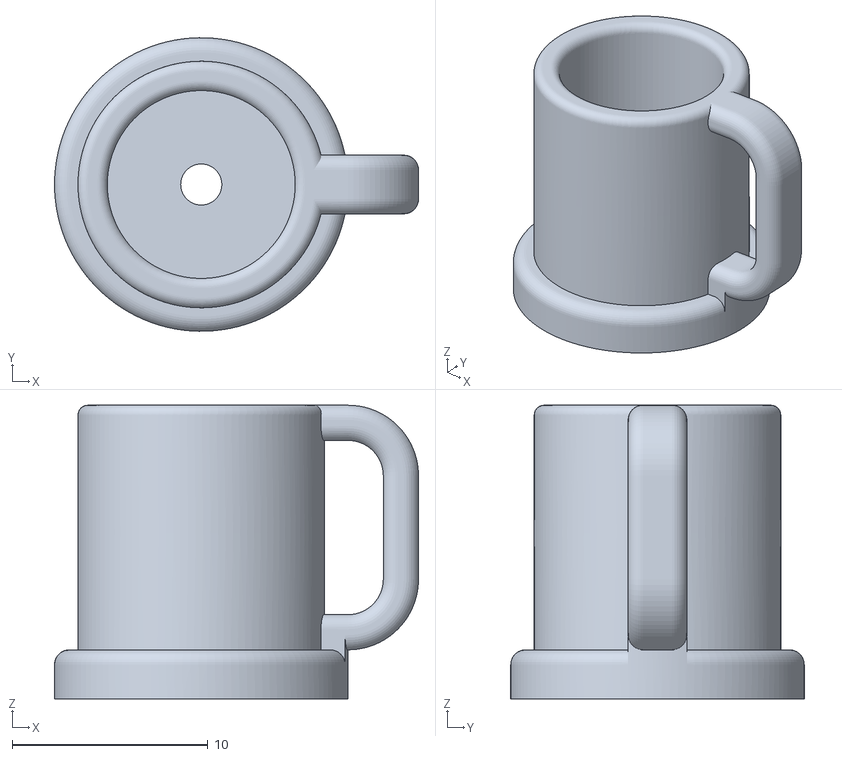
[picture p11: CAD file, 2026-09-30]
mein-build/tasse/Tasse_Tasse.stl
18.6 x 15.0 x 15.0

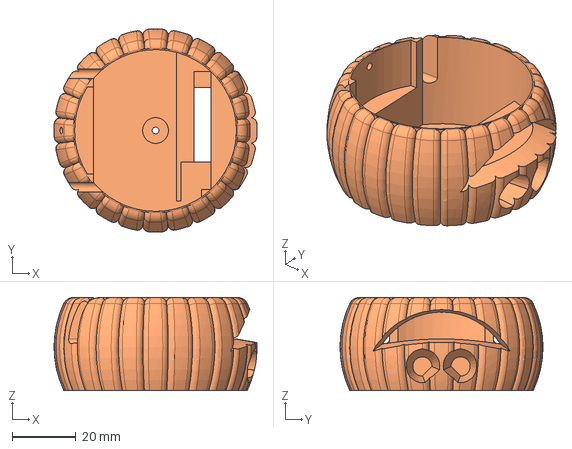
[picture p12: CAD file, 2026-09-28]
mods/halloween/3d_models/parts/hd1370a/step/PumpkinCover.step
63.7 x 63.8 x 29.2 mm

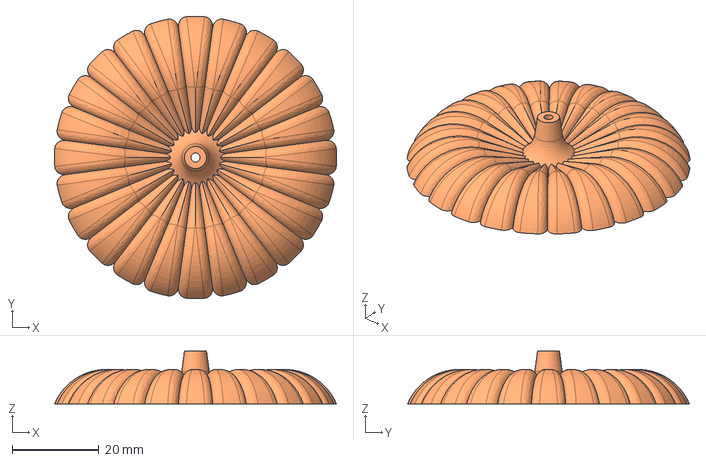
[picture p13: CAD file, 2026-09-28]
mods/halloween/3d_models/parts/sg90/step/PumpkinTop.step
65.2 x 65.2 x 12.2 mm

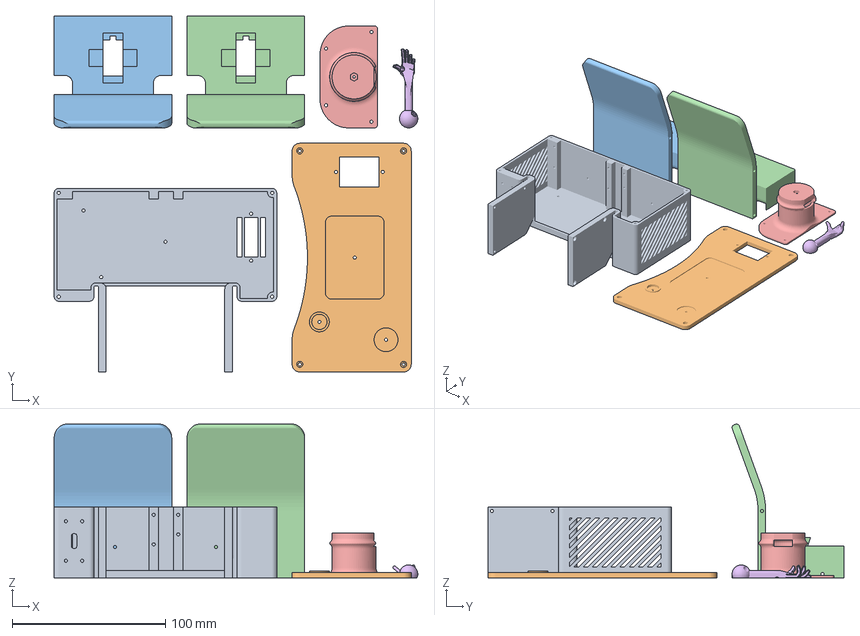
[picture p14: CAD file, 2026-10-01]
mein-build/druckprojekte/TinyEngineer_03_Schwarz_1.3mf
237.5 x 232.5 x 100.5 mm
Desk_1
DeskTop_1
Chair_1
Chair_2
Belly_1
ForearmLeft_1

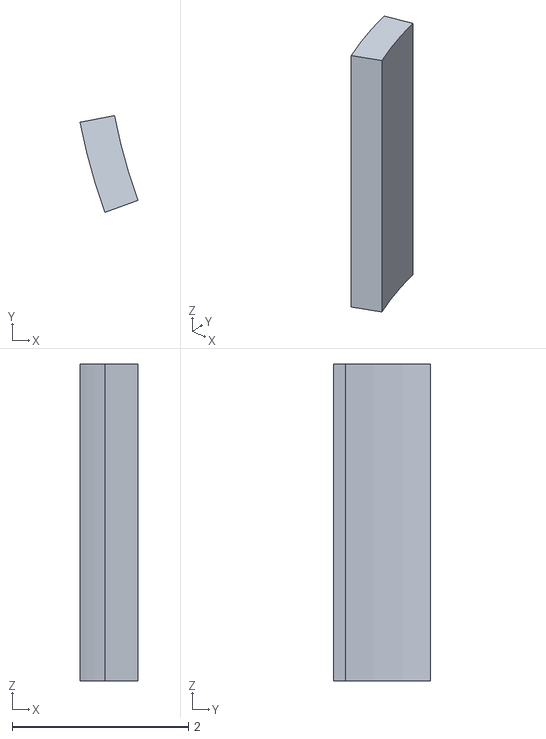
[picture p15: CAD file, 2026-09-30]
mein-build/tasse/Tasse_Schrift_3.stl
0.659 x 1.10 x 3.60

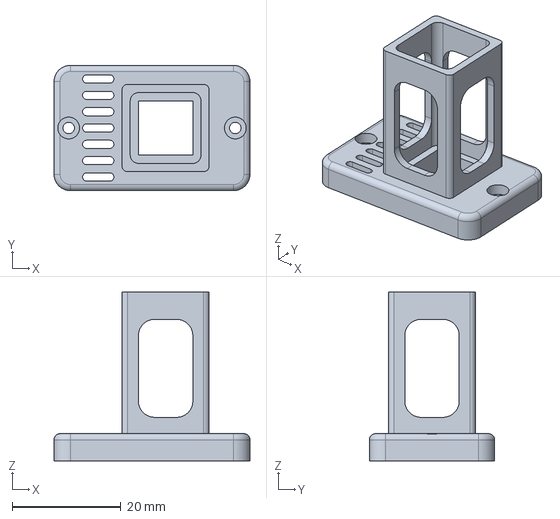
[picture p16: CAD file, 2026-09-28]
mods/halloween/3d_models/parts/sg90/step/LampBase.step
36.0 x 23.0 x 31.0 mm

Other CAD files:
mods/halloween/3d_models/parts/fs0307/step/LampCap.step
mods/halloween/3d_models/parts/fs0307/step/LampDiffuser.step
mods/halloween/3d_models/parts/hd1370a/step/LampDiffuser.step
mein-build/druckprojekte/TinyEngineer_06_AluSilber.3mf
mein-build/druckprojekte/TinyEngineer_01_Testteile.3mf
mein-build/druckprojekte/TinyEngineer_02_Weiss.3mf
mein-build/druckprojekte/TinyEngineer_04_Kupfer.3mf
mein-build/druckprojekte/TinyEngineer_05_Anthrazit.3mf
mein-build/druckprojekte/TinyEngineer_07_Glasplatte.3mf
mein-build/druckprojekte/TinyEngineer_09_Klingel_Silber.3mf
mein-build/druckprojekte/TinyEngineer_10_Lampenknopf_Rot.3mf
mein-build/tasse/Tasse_Herz.stl
mein-build/tasse/Tasse_Schrift_1.stl
mein-build/tasse/Tasse_Schrift_2.stl
mods/halloween/3d_models/cad/TinyEngineerHalloween.f3d
mods/halloween/3d_models/parts/fs0307/3mf/Head.3mf
mods/halloween/3d_models/parts/fs0307/3mf/LampBase.3mf
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

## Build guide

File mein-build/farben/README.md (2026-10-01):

# Farben für meinen Tiny Engineer

Vorschauen sind aus einem Foto des Originals umgefärbt, keine echten Drucke. Die Mengen stammen aus Bambu Studio (P2S, 0,16 mm, 20 % Füllung) und gelten pro Roboter.

| Bild | Inhalt |
| --- | --- |
| [farbideen.jpg](farbideen.jpg) | Neun Farbkombinationen zur Auswahl |
| [variante1-bambu.jpg](variante1-bambu.jpg) | Variante 1: Weiß, Schwarz, Silbergrau, Anthrazit, blaugraues „Glas“ |
| [variante2-fusion.png](variante2-fusion.png) | Variante 2 im CAD-Modell (Fusion) |
| [variante2-tasse.png](variante2-tasse.png) | Tasse „I ♥ IT“ im CAD-Modell |
| [variante2-bildschirm.png](variante2-bildschirm.png) | Laptop-Bildschirm mit Konsole |
| [variante2-realistisch.jpg](variante2-realistisch.jpg) | Aktueller Stand von Variante 2 als Foto-Vorschau (Tisch RAL 7016) |
| [variante2-foto-schraeg.jpg](variante2-foto-schraeg.jpg) | Schrägansicht: Original und aktueller Stand |
| [variante2-dasfilament.jpg](variante2-dasfilament.jpg) | Variante 2: Farben von dasfilament.de, Tasse „I ♥ IT“ |

## Variante 2 (dasfilament.de)

| Teile | Farbe | Filament | pro Roboter |
| --- | --- | --- | --- |
| Head, Chest, Hat, Belly, Neck, Mug (mit Henkel), AiEmblem (Logo), Konsolenschrift | Weiß | PLA Weiß | 60 g |
| UpperArm (2×), ForearmLeft/Right, Coffee (Tasseninhalt), LaptopScreen (Bildschirm), Chair, SeatLeft, SeatRight, Schrift auf der Tasse | Schwarz | PLA Schwarz | 79 g |
| Desk (Tischkorpus), DeskPad (Unterplatte mit Ecken), LampBase | Anthrazitgrau | PETG RAL 7016 | 90 g |
| LaptopCase, LampCap | Alu-Silber | PETG Alu-Silber | 13 g |
| Bell (Klingel) | Silber | PLA Silber | < 1 g |
| DeskTop (Tischplatte ohne unterste 0,36 mm), LampDiffuser (Lampenschirm) | Glas | PETG Natur (glasklar) | 34 g |
| DeskTop, unterste 0,36 mm (2 Schichten) | Blauschimmer | PETG Transparent Blau | 5 g |
| Herz auf der Tasse, LampButton | Feuerrot | PLA Feuerrot | < 1 g |

Bestellung bei dasfilament.de für die ersten zwei Roboter: Roboter 1 im Original (Kupfer/Schwarz), Roboter 2 in
Variante 2. Die Farbe von Roboter 3 steht noch nicht fest (1,75 mm, Preise vom 01.10.2026):

| Filament | Link | Bedarf für 2 Roboter | Kauf | Preis |
| --- | --- | --- | --- | --- |
| PLA Weiß | [1 kg](https://dasfilament.de/produkt/pla-filament-175-mm-weiss-1-kg/) | 89 g (inkl. Testteile) | 1 kg | 15,99 € |
| PLA Schwarz | [1 kg](https://dasfilament.de/produkt/pla-filament-175-mm-schwarz-1-kg/) | 282 g | 1 kg | 15,99 € |
| PETG Burnt Copper (Original) | [1 kg](https://dasfilament.de/produkt/petg-filament-175-mm-burnt-copper-1-kg/) | 72 g | 1 kg | 21,00 € |
| PETG RAL 7016 Anthrazitgrau | [1 kg](https://dasfilament.de/produkt/petg-filament-175-mm-7016-1-kg/) | 91 g | 1 kg | 21,00 € |
| PETG Natur | [1 kg](https://dasfilament.de/produkt/petg-filament-175-mm-natur-1-kg/) | 43 g | 1 kg | 21,00 € |
| PETG Alu-Silber | [Probe](https://dasfilament.de/produkt/petg-filament-50-g-sample-175-mm-alu-silber/) | 13 g | 50 g | 2,95 € |
| PLA Feuerrot | [Probe](https://dasfilament.de/produkt/pla-filament-175-mm-feuerrot-50-g-sample/) | 7 g (fast nur Spülmenge) | 50 g | 2,95 € |
| PLA Silber | [Probe](https://dasfilament.de/produkt/pla-filament-175-mm-silber-50-g-sample/) | < 1 g | 50 g | 2,95 € |
| PETG Transparent Blau | [Probe](https://dasfilament.de/produkt/petg-filament-50-g-sample-175-mm-transparent-blau/) | 3 g | 50 g | 2,95 € |
| **Filament gesamt** | | | | **106,78 €** |
| Farbmuster-Set, optional (68 Plättchen) | [Set](https://dasfilament.de/produkt/farbplaettchen-farbmuster-set-swatches/) | – | 1 | 19,94 € |

Die Proben kommen als loser Ring ohne Spule. Zum Drucken auf eine leere 1-kg-Spule wickeln.
Für das Original passt PETG Burnt Copper besser zum Seiden-Kupfer als PLA Bronze (wirkt eher goldbraun).

Versandkosten stehen erst im Warenkorb. Das Farbmuster-Set zeigt jede Farbe in Stufen von 0,2 bis 2 mm Dicke; damit lässt sich prüfen, wie klar PETG Natur in Plattenstärke wirkt.

## Druckprojekte

Fertige Bambu-Studio-Projekte für Roboter 1 (Original) und Roboter 2 (Variante 2): [../druckprojekte/](../druckprojekte/README.md).

## Slicer-Profile

DAS FILAMENT bietet Profile für Bambu Studio (PLA, PETG, TPU; alle Bambu-Drucker, auch P2S 0,4 mm): [dasfilament.de/slicer-profile](https://dasfilament.de/slicer-profile/). Import: Datei → Importieren → „Konfigurationen importieren …“ mit der ZIP-Datei. Die Rollen haben keinen RFID-Chip, das Profil im AMS einmal pro Fach wählen.

## Druckhinweise

- **Material je Druckteil:** In keinem Teil treffen PLA und PETG aufeinander; PLA und PETG haften schlecht aneinander.
- **PETG** haftet auf glatten Druckplatten sehr stark: strukturierte Platte oder Trennmittel verwenden.
- **Glasplatte:** mit 100 % Füllung drucken, sonst sieht man das Füllmuster durch das klare PETG. Die untersten 0,36 mm (erste Schicht 0,2 mm plus eine 0,16-mm-Schicht) sind PETG Transparent Blau und geben einen leichten Blauschimmer; die Gesamtdicke ist unverändert. Druckdatei [../tischplatte/Tischplatte_Blauschicht_Teile.3mf](../tischplatte/Tischplatte_Blauschicht_Teile.3mf) (ein Objekt, zwei Teile); ein einziger Farbwechsel. Darunter liegen Unterplatte und geschlossener Tischkorpus in Anthrazitgrau, Elektronik sieht man nicht.
- **Bildschirm:** Konsole „$ ./hello / Hello human! / What are we / building today?“ in Consolas Fett, 2,6 mm hoch, weiß auf schwarz, 0,36 mm tief eingelegt. Die Bildschirmseite liegt beim Druck auf dem Bett; Farbwechsel nur in den ersten zwei Schichten. Druckdatei [../bildschirm/Bildschirm_Konsole_Teile.3mf](../bildschirm/Bildschirm_Konsole_Teile.3mf). Die Striche sind nur ~0,35 mm breit; in der Slicer-Vorschau prüfen, ob alle Zeichen gedruckt werden.
- **Tasse „I ♥ IT“:** Dateien in [../tasse/](../tasse/). Schrift und Herz sind 0,4 mm erhaben, gegenüber dem Henkel; der Henkel zeigt beim Einsetzen nach hinten. `Tasse_ILoveIT_Teile.3mf` öffnet Bambu Studio als ein Objekt mit fünf Teilen (Tasse, Herz, drei Buchstaben). Die Tasse liegt mit den Konsolen-Bildschirmen auf einer Platte (Druckprojekt 08).
- **Tisch:** Original-Druckdatei `Desk.3mf`, einfarbig in RAL 7016.
- **Klingel:** Den Knopf oben bildet der Kopf der M2×16-Schraube, mit der die Klingel am Tisch befestigt wird.
- **Lampensockel** bleibt deckend (Anthrazitgrau): Er sitzt über dem ESP32, durchsichtig sähe man die Platine.

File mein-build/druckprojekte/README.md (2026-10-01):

# Druckprojekte für zwei Tiny Engineer: Original (Kupfer/Schwarz) und Variante 2

Welches Teil gehört zu welchem Roboter:

- **Roboter 1, Original:** Kopf, Brust, Hut, Logo, Laptopgehäuse, Unterplatte, Lampensockel, Lampenhut, Lampenknopf,
  Tasse und Klingel in Kupfer (PETG Burnt Copper). Bauch, Hals, Tischkorpus und Tischplatte in Schwarz. Lampenschirm
  weiß. Bildschirm wie bei Variante 2 mit Konsole (Platte 08).
- **Roboter 2, Variante 2:** Farben wie in [../farben/README.md](../farben/README.md).
- **Für beide schwarz:** Stuhl, Sitzschalen, Arme, Kaffee.
- **Roboter 3** kommt später, seine Farbe steht noch nicht fest.

Fertige Projekte für Bambu Studio, je eine Druckplatte. Drucker Bambu Lab P2S, 0,4-mm-Düse, 0,16 mm Schichthöhe,
strukturierte PEI-Platte, Filamentprofile „DAS FILAMENT“ (PLA/PETG). Zeiten und Gramm aus Bambu Studio, inklusive
Spülmenge und Reinigungsturm bei mehrfarbigen Platten.

**Druckkopf und andere Teile:** Alle Platten drucken schichtweise („by layer“), der Kopf fährt nie unter die aktuelle
Schicht. Zwischen den Teilen sind mindestens 10 mm Abstand, „Wände nicht überqueren“ ist an. Bei mehrfarbigen Platten
bleibt oben rechts Platz für den Reinigungsturm.

**Vor dem Druck:** Projekt öffnen, im AMS die Rollen wie in Spalte „AMS“ einlegen (Fachnummer = Filament im Projekt),
die Zuordnung in Bambu Studio prüfen, slicen, drucken. Mit dem Testteile-Projekt anfangen.

| Projekt | Teile | AMS (Fach: Filament) | Zeit, Gramm je Filament | Hinweise |
| --- | --- | --- | --- | --- |
| [01_Testteile](TinyEngineer_01_Testteile.3mf) | Schrauben-Testteil, Servo-Testteil | 1: PLA Weiß | 0:49 h, 16 g | – |
| [02_Weiss](TinyEngineer_02_Weiss.3mf) | Logo, Bauch, Brust, Hut, Kopf, Lampenschirm, Hals | 1: PLA Weiß | 2:25 h, 57 g | – |
| [03_Schwarz_1](TinyEngineer_03_Schwarz_1.3mf) | Bauch, Stuhl, Tischkorpus, Tischplatte, Unterarm links | 1: PLA Schwarz | 7:12 h, 224 g | – |
| [03_Schwarz_2](TinyEngineer_03_Schwarz_2.3mf) | Kaffee, Unterarm links, Unterarm rechts, Hals, Sitzschale links, Sitzschale rechts, Oberarm | 1: PLA Schwarz | 1:52 h, 44 g | – |
| [04_Kupfer](TinyEngineer_04_Kupfer.3mf) | Logo, Klingel, Brust, Unterplatte, Hut, Kopf, Lampensockel, Lampenknopf, Lampenhut, Laptopgehäuse, Tasse | 1: PETG Burnt Copper | 3:17 h, 72 g | PETG |
| [05_Anthrazit](TinyEngineer_05_Anthrazit.3mf) | Tischkorpus, Unterplatte, Lampensockel | 1: PETG RAL 7016 | 3:41 h, 91 g | PETG |
| [06_AluSilber](TinyEngineer_06_AluSilber.3mf) | Lampenhut, Laptopgehäuse | 1: PETG Alu-Silber | 0:59 h, 13 g | PETG |
| [07_Glasplatte](TinyEngineer_07_Glasplatte.3mf) | Lampenschirm, Glas-Tischplatte | 1: PETG Natur, 2: PETG Transparent Blau | 1:06 h, 43 + 2 g | 100 % Füllung, PETG |
| [08_Tasse_Bildschirm](TinyEngineer_08_Tasse_Bildschirm.3mf) | Bildschirm mit Konsole, Tasse „I ♥ IT“ | 1: PLA Weiß, 2: PLA Schwarz, 3: PLA Feuerrot | 2:04 h, 16 + 14 + 6 g | – |
| [09_Klingel_Silber](TinyEngineer_09_Klingel_Silber.3mf) | Klingel | 1: PLA Silber | 0:03 h, < 1 g | – |
| [10_Lampenknopf_Rot](TinyEngineer_10_Lampenknopf_Rot.3mf) | Lampenknopf | 1: PLA Feuerrot | 0:01 h, < 1 g | – |

**Summe:** 23:29 h reine Druckzeit.

Verbrauch je Filament (alle Projekte):

| Filament | Gramm |
| --- | --- |
| PETG Alu-Silber | 13 |
| PETG Burnt Copper | 72 |
| PETG Natur | 43 |
| PETG RAL 7016 | 91 |
| PETG Transparent Blau | 2 |
| PLA Feuerrot | 6 |
| PLA Schwarz | 282 |
| PLA Silber | 0 |
| PLA Weiß | 89 |

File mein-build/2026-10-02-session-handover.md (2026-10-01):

# Session-Handover 2026-10-02

Stichworte: Upstream-Issues und PR-Reviews (#31 behoben, #46 geprüft), Fusion-MCP eingerichtet, Farbvariante 2
mit eigenen Teilen (Tasse „I ♥ IT“, Konsolen-Bildschirm, Glas-Tischplatte), Einkaufsliste, Bambu-Studio-Druckprojekte
für Roboter 1 (Original) und Roboter 2 (Variante 2). Diese Datei dient als Übergabe an die nächste Session.

---

## Ausgangslage

- Repo `D:\workspace\tiny-engineer`, Klon von `jamro/tiny-engineer`; Remote `fork` = `awi81/tiny-engineer`.
- Branches:
  - `fix/keyboard-cut-profile` (`a7d5b9b`): Fix für Issue #31, offen als PR jamro/tiny-engineer#52.
  - `awi/farbvarianten` (auf dem Fork): eigener Bau, Ordner `mein-build/`. Wird nicht upstream vorgeschlagen.
  - `main`: 8 Commits hinter `origin/main`.
- Der Nutzer baut drei Roboter nacheinander (Modul-Variante, SG90). Drucker Bambu Lab P2S Combo (mit AMS) ist noch
  nicht gekauft, Bestellung von Elektronik und Filament steht bevor.

---

## Erledigt in dieser Session

| Commit | Bereich | Was |
|---|---|---|
| `a7d5b9b` | `3d_models/fusion/TinyEngineerTools/servo.py` | Laptop-Tasten bleiben beim Wechsel auf größeren Servo erhalten (Issue #31); PR #52 |
| – | jamro/tiny-engineer#46 | PCB-Review als Kommentar gepostet; jamro hat sich bedankt, prüft ~OE/GP5 zuerst |
| `3cb8f99` … `ae3c0c8` | `mein-build/farben`, `tasse`, `tischplatte`, `bildschirm` | Variante 2: Farben, eigene Teile, Vorschaubilder, Bestellliste |
| `6ca8049` | `mein-build/druckprojekte` | 15 Platten für drei V2-Roboter (abgelöst) |
| `f91f13e` | `mein-build/druckprojekte`, `farben/README.md` | 11 Platten für Roboter 1 (Original, PETG Burnt Copper) + Roboter 2 (V2), Bestellung 106,78 € |
| `4afadb8` | `mein-build/druckprojekte` | Original-Roboter bekommt auch den Konsolen-Bildschirm |

Außerhalb des Repos:

- Einkaufsliste (Word): `D:\workspace_temp\tiny-engineer\einkaufsliste\Tiny-Engineer-Einkaufsliste.docx`
  (Generator `build.js`); Elektronik für drei, Filament für zwei Roboter, gesamt ~267 €.
- Generator der Druckprojekte: `D:\workspace_temp\tiny-engineer\projekte\build_projects.py`
  (`TE_SET=2bots`, Ausgabe `out_2bots`), Übersicht `make_readme.py`.
- Fusion-Modell Variante 2: `D:\workspace_temp\tiny-engineer\fusion\TinyEngineer_variante2.f3d`.

---

## Offene Punkte für die nächste Session

### 1. Nach Lieferung des Druckers: Testteile

- Platte `01_Testteile` drucken. ServoSizingTester muss einen SG90 ohne Gewalt aufnehmen.
- ScrewSizingTest: Weicht der passende Lochdurchmesser von 2,1 mm ab, den Fusion-Parameter
  `screw_thread_diameter` ändern, Teile neu exportieren und `build_projects.py` mit `TE_SET=2bots` neu laufen lassen.

### 2. Proben ohne Spule

- 50-g-Proben von dasfilament sind lose Ringe. Für AMS auf eine leere 1-kg-Spule wickeln (Feuerrot für die Tasse,
  Transparent Blau für die Glasplatte).

### 3. Roboter 3

- Farbe offen. Wenn sie feststeht: neuen Plattensatz in `build_projects.py` anlegen (wie `PLATES_2BOTS`).

### 4. Upstream (nur auf Nachfrage)

- PR #52: nur zwei Bot-Hinweise (CodeRabbit, Randfall „Execute error“). Entscheidung: abwarten, bis jamro reagiert.
- PR #46: nichts zu tun.

### 5. Zurückgestellt

- Idee: Steuerung per USB statt WLAN (Memory `idea-usb-serial-control`).

---

## Wichtige Konventionen aus dieser Session (Memory-relevant)

- Upstream nur nach gezeigtem Entwurf und ausdrücklicher Freigabe posten; Pushes nur auf `fork`. Steht in Memory
  `no-upstream-posting`.
- Stand des Baus, Dateiorte und Stolperfallen der Bambu-Studio-CLI stehen in Memory `build-plan-3-robots`.

---

## Aktionen in der neuen Session — Empfehlung

1. Nach Lieferung: `D:\workspace\tiny-engineer\mein-build\druckprojekte\README.md` (Branch `awi/farbvarianten`)
   öffnen und mit Platte 01 starten; Ergebnis des Schrauben-Tests auswerten.
2. Bei Bedarf Schraubenmaß in Fusion ändern und Druckprojekte neu erzeugen.
3. Verdrahten (`docs/hardware/wiring.md`), flashen (`docs/flash.md`), montieren (`docs/3d/assembly.md`).

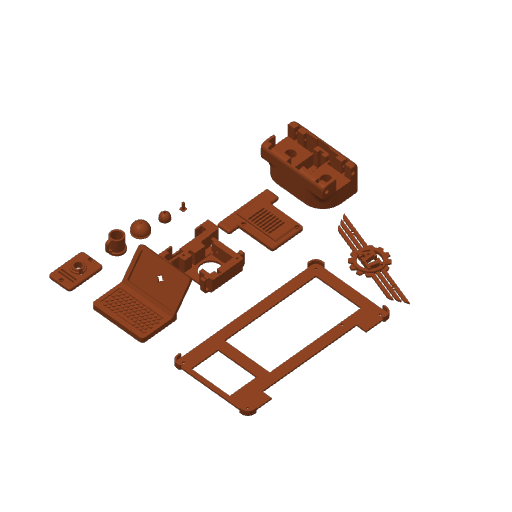
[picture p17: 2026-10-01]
mein-build/druckprojekte/TinyEngineer_04_Kupfer.png

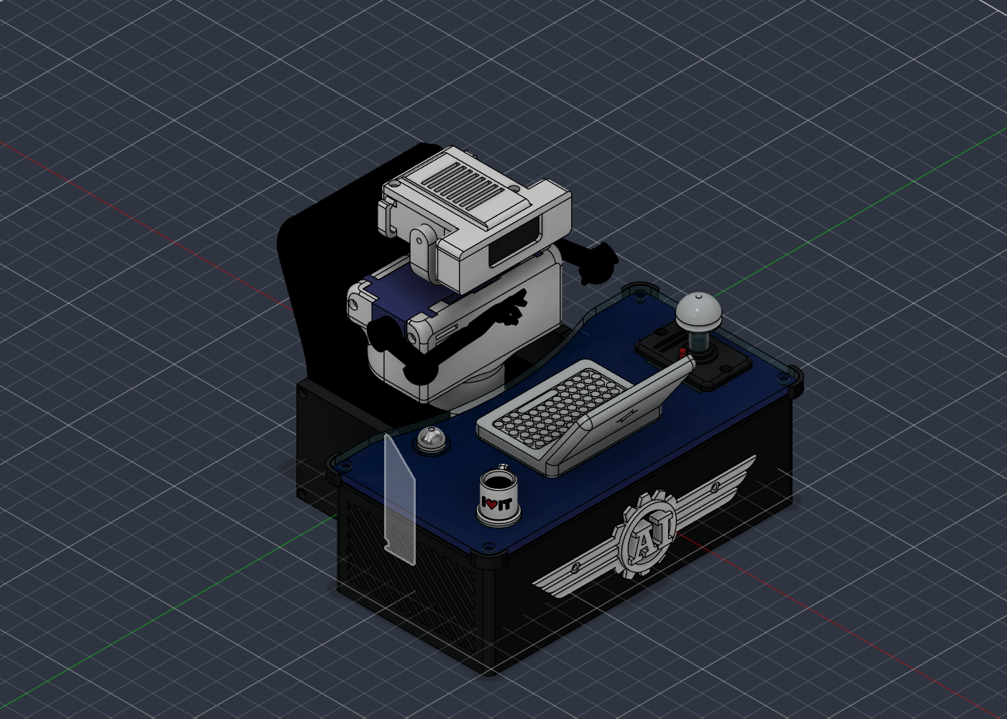
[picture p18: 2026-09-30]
mein-build/farben/variante2-fusion.png

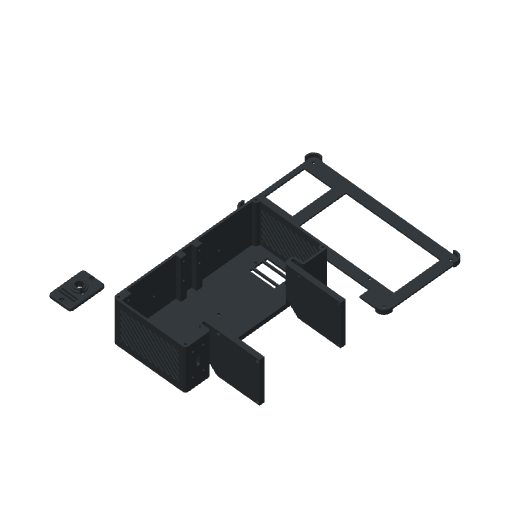
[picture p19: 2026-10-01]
mein-build/druckprojekte/TinyEngineer_05_Anthrazit.png

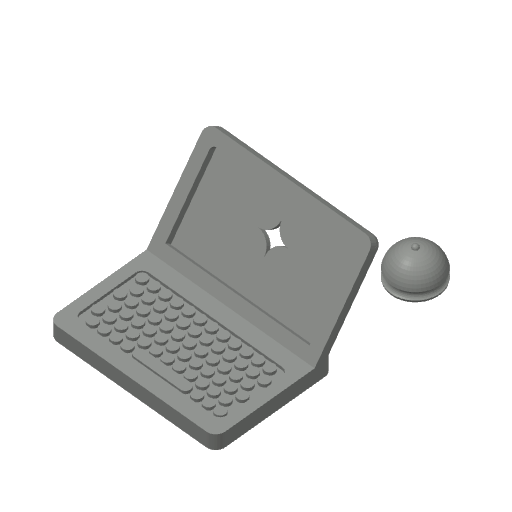
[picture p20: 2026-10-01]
mein-build/druckprojekte/TinyEngineer_06_AluSilber.png

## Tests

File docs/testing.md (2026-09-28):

# Tests

Host checks. These commands do not flash the board. GitHub Actions on `main` and PRs runs these same commands (firmware, packages, and PCB). On-device hardware: [hardware/testing.md](hardware/testing.md).

## Firmware

Unity on the host. Compiles `src/settings/validate.cpp` plus header-only helpers such as [`include/servos.h`](../include/servos.h).

```bash
pio test -e native
python3 scripts/test_audio_pack.py
```

`pio run` builds firmware. Native tests are **`pio test -e native`**, not `pio run -e native`. `scripts/test_audio_pack.py` checks the stock WAV copy and mod overlay (no PlatformIO, no hardware).

## OLED expressions

The optional [expression library](../lib/TinyEngineerExpressions/README.md) has deterministic asset checks and native renderer tests. These checks require Node 18+ and PlatformIO; they do not access hardware. On the robot, enable those faces with Config / `eyes_style=kaomoji` (default remains `classic`).

```bash
node scripts/expressions/generate.js --check
node scripts/expressions/test-assets.js
pio test -e native
pio run -e expression-demo
```

The `expression-demo` environment builds a separate OLED-only application without changing the default robot build. For a later bench test, follow its [wiring and upload notes](../lib/TinyEngineerExpressions/README.md#standalone-oled-demo), leave the separate servo supply off, and observe all 16 faces through a complete 48-second cycle. Report physical display results separately from host tests and compilation.

## Packages

Node 18+. No robot.

```bash
npm test --prefix packages/tiny-engineer-cursor
npm test --prefix packages/tiny-engineer-antigravity
npm test --prefix packages/tiny-engineer-claude-code
```

## PCB

KiCad 10 (`kicad-cli`). Stdlib Python only — no pip packages. ERC (errors), DRC (errors + schematic parity), and `expected-nets.yml` for every board under `hardware/boards/`.

```bash
python3 scripts/check_pcb.py
```

Optional: `python3 scripts/check_pcb.py main-control-board --report-dir artifacts/pcb`. Details: [pcb.md](pcb.md). On-device hardware: [hardware/testing.md](hardware/testing.md).

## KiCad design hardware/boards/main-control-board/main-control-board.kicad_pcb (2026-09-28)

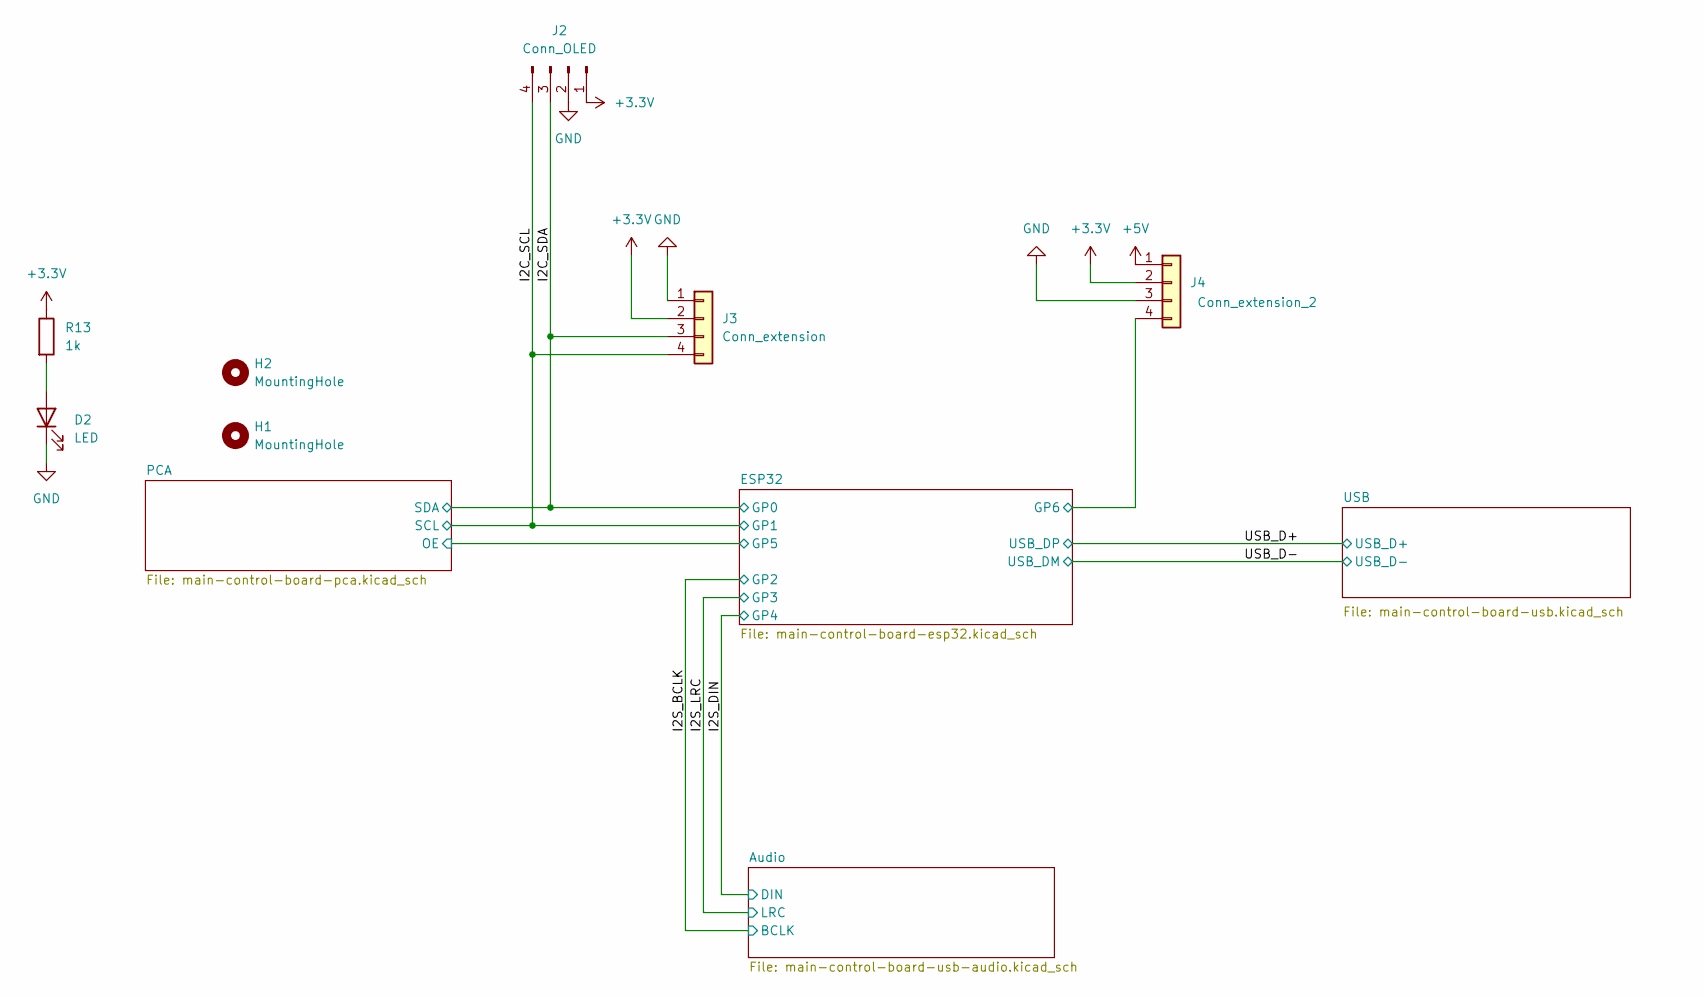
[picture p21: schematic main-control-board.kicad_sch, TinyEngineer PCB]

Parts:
D2: LED; LED_0603_1608Metric; LCSC Part # C2286
H1, H2: MountingHole; MountingHole_2.2mm_M2
J2: Conn_OLED; PinHeader_1x04_P2.54mm_Vertical; LCSC Part # C2691448
J3: Conn_extension; JST_SH_SM04B-SRSS-TB_1x04-1MP_P1.00mm_Horizontal; LCSC Part # C160404
J4: Conn_extension_2; PinHeader_1x04_P2.54mm_Vertical
R13: 1k; R_0603_1608Metric; LCSC Part # C21190

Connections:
+3.3V: J2.1, J3.2, J4.2, R13.1; also elsewhere on the board
+5V: J4.1; also elsewhere on the board
/ESP32/GP6: J4.4; also elsewhere on the board
/I2C_SCL: J2.4, J3.4; also elsewhere on the board
/I2C_SDA: J2.3, J3.3; also elsewhere on the board
GND: D2.1 (K), J2.2, J3.1, J4.3; also elsewhere on the board
unnamed: D2.2 (A), R13.2

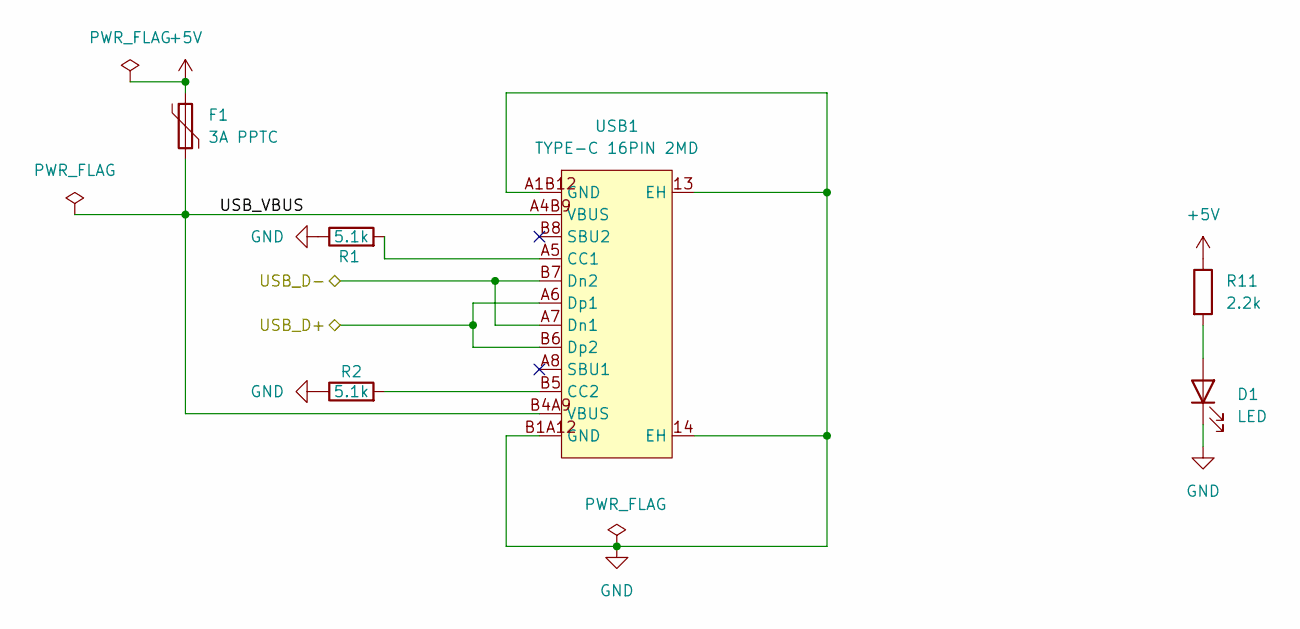
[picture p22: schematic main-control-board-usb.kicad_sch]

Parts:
D1: LED; LED_0603_1608Metric; LCSC Part # C2286
F1: 3A PPTC; Fuse_1812_4532Metric; LCSC Part # C883162
R1, R2: 5.1k; R_0603_1608Metric; LCSC Part # C23186
R11: 2.2k; R_0603_1608Metric; LCSC Part # C4190
USB1: TYPE-C 16PIN 2MD; USB-C-SMD_TYPE-C-16PIN-2MD-073; MPN TYPE-C 16PIN 2MD(073); LCSC Part # C2765186

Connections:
+5V: F1.1, R11.1; also elsewhere on the board
/USB/USB_VBUS: F1.2, USB1.A4B9 (VBUS), USB1.B4A9 (VBUS)
/USB_D+: USB1.A6 (Dp1), USB1.B6 (Dp2); also elsewhere on the board
/USB_D-: USB1.A7 (Dn1), USB1.B7 (Dn2); also elsewhere on the board
GND: D1.1 (K), R1.1, R2.1, USB1.13 (EH), USB1.14 (EH), USB1.A1B12 (GND), USB1.B1A12 (GND); also elsewhere on the board
unnamed: D1.2 (A), R11.2
unnamed: R1.2, USB1.A5 (CC1)
unnamed: R2.2, USB1.B5 (CC2)

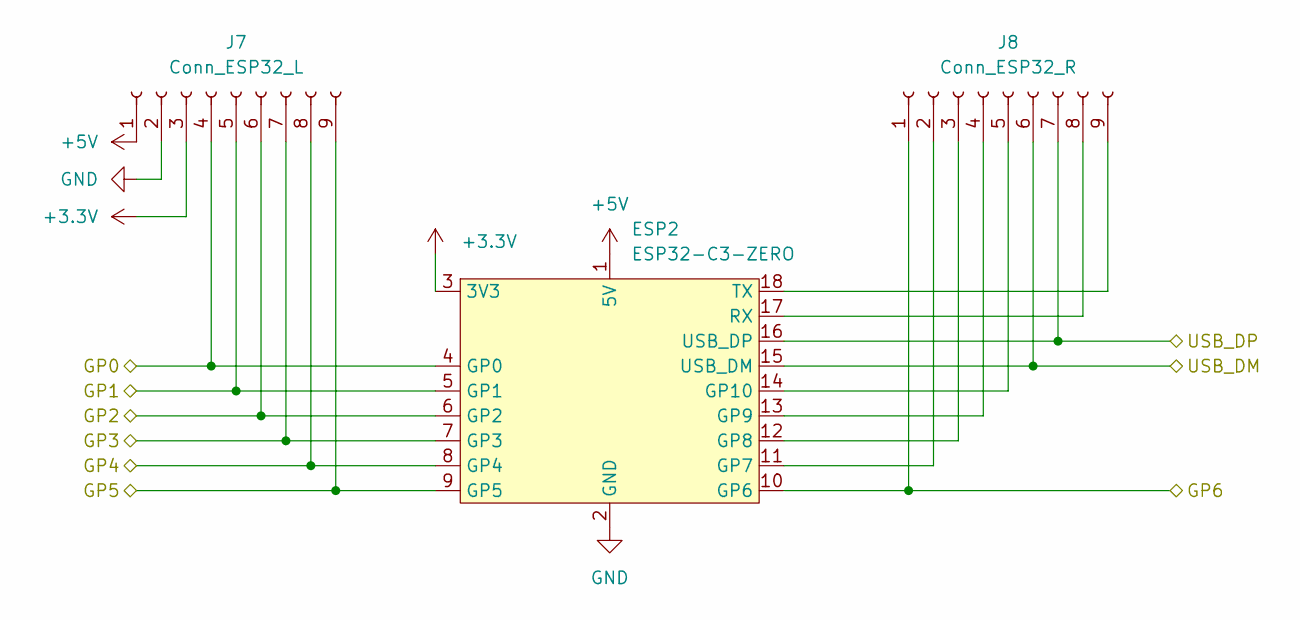
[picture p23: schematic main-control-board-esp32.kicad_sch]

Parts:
ESP2: ESP32-C3-ZERO; ESP32_C3_Zero_Dev_Board
J7: Conn_ESP32_L; PinSocket_1x09_P2.54mm_Vertical; LCSC Part # C2897372
J8: Conn_ESP32_R; PinSocket_1x09_P2.54mm_Vertical; LCSC Part # C2897372

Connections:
+3.3V: ESP2.3 (3V3), J7.3; also elsewhere on the board
+5V: ESP2.1 (5V), J7.1; also elsewhere on the board
/ESP32/GP5: ESP2.9 (GP5), J7.9; also elsewhere on the board
/ESP32/GP6: ESP2.10 (GP6), J8.1; also elsewhere on the board
/I2C_SCL: ESP2.5 (GP1), J7.5; also elsewhere on the board
/I2C_SDA: ESP2.4 (GP0), J7.4; also elsewhere on the board
/I2S_BCLK: ESP2.6 (GP2), J7.6; also elsewhere on the board
/I2S_DIN: ESP2.8 (GP4), J7.8; also elsewhere on the board
/I2S_LRC: ESP2.7 (GP3), J7.7; also elsewhere on the board
/USB_D+: ESP2.16 (USB_DP), J8.7; also elsewhere on the board
/USB_D-: ESP2.15 (USB_DM), J8.6; also elsewhere on the board
GND: ESP2.2 (GND), J7.2; also elsewhere on the board
unnamed: ESP2.11 (GP7), J8.2
unnamed: ESP2.12 (GP8), J8.3
unnamed: ESP2.13 (GP9), J8.4
unnamed: ESP2.14 (GP10), J8.5
unnamed: ESP2.17 (RX), J8.8
unnamed: ESP2.18 (TX), J8.9

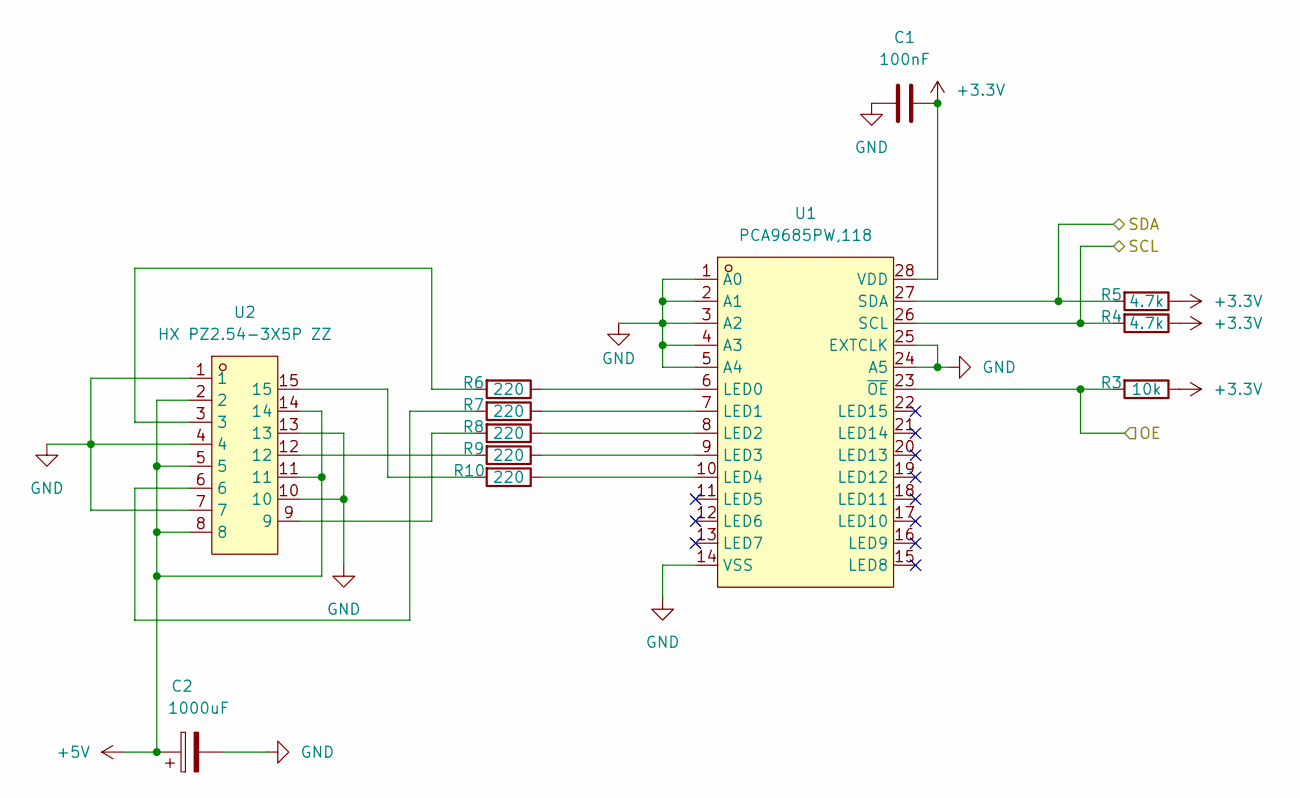
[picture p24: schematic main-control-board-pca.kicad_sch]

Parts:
C1: 100nF; C_0603_1608Metric; LCSC Part # C14663
C2: 1000uF; CP_Elec_10x10.5; LCSC Part # C46550395
R3: 10k; R_0603_1608Metric; LCSC Part # C25804
R4, R5: 4.7k; R_0603_1608Metric; LCSC Part # C23162
R6, R7, R8, R9, R10: 220; R_0603_1608Metric; LCSC Part # C22962
U1: PCA9685PW,118; TSSOP-28_L9.7-W4.4-P0.65-LS6.4-TL; MPN PCA9685PW,118; LCSC Part # C2678753
U2: HX PZ2.54-3X5P ZZ; HDR-TH_15P-P2.54-V-M-R3-C5-S7.5; MPN HX PZ2.54-3x5P ZZ; LCSC Part # C32713292

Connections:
+3.3V: C1.2, R3.1, R4.1, R5.1, U1.28 (VDD); also elsewhere on the board
+5V: C2.1, U2.2, U2.5, U2.8, U2.11, U2.14; also elsewhere on the board
/ESP32/GP5: R3.2, U1.23 (~OE); also elsewhere on the board
/I2C_SCL: R4.2, U1.26 (SCL); also elsewhere on the board
/I2C_SDA: R5.2, U1.27 (SDA); also elsewhere on the board
GND: C1.1, C2.2, U1.1 (A0), U1.2 (A1), U1.3 (A2), U1.4 (A3), U1.5 (A4), U1.14 (VSS), U1.24 (A5), U1.25 (EXTCLK), U2.1, U2.4, U2.7, U2.10, U2.13; also elsewhere on the board
unnamed: R6.2, U2.3
unnamed: R7.2, U2.6
unnamed: R8.2, U2.9
unnamed: R9.2, U2.12
unnamed: R10.2, U2.15
unnamed: R6.1, U1.6 (LED0)
unnamed: R7.1, U1.7 (LED1)
unnamed: R8.1, U1.8 (LED2)
unnamed: R9.1, U1.9 (LED3)
unnamed: R10.1, U1.10 (LED4)

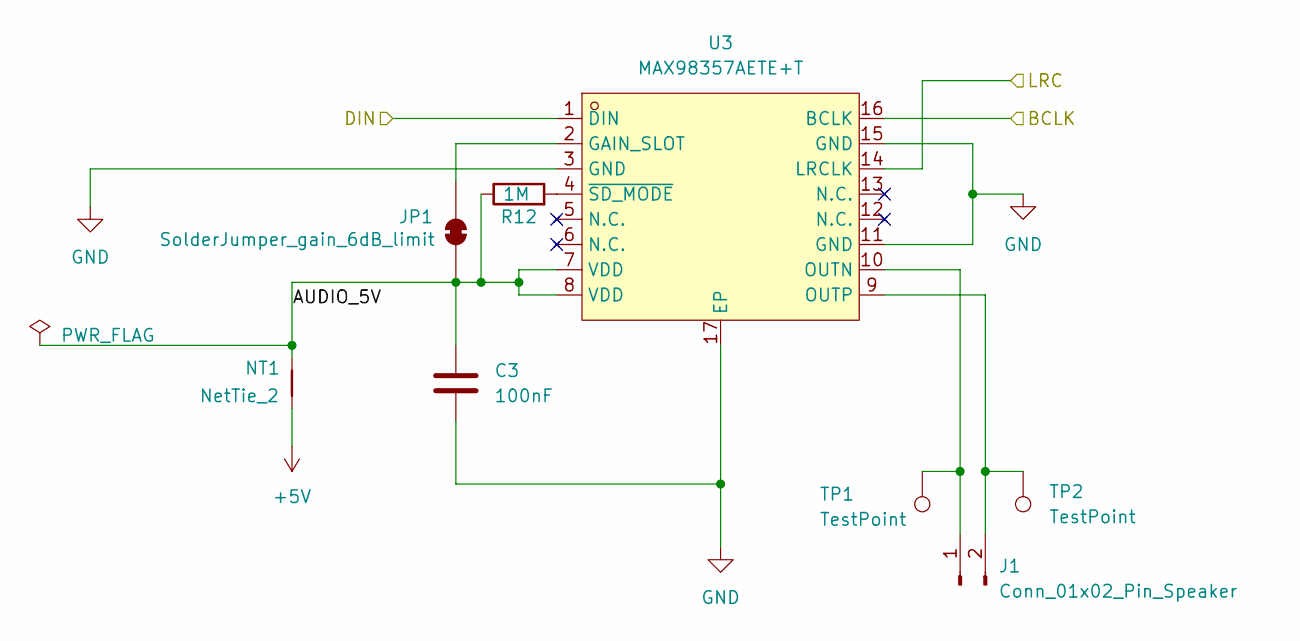
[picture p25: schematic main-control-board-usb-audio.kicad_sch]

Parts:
C3: 100nF; C_0603_1608Metric; LCSC Part # C14663
J1: Conn_01x02_Pin_Speaker; Molex_PicoBlade_53261-0271_1x02-1MP_P1.25mm_Horizontal; LCSC Part # C2845379
JP1: SolderJumper_gain_6dB_limit; SolderJumper-2_P1.3mm_Bridged_RoundedPad1.0x1.5mm
NT1: NetTie_2; NetTie-2_SMD_Pad2.0mm
R12: 1M; R_0603_1608Metric; LCSC Part # C22935
TP1, TP2: TestPoint; SolderWire-0.25sqmm_1x01_D0.65mm_OD2mm
U3: MAX98357AETE+T; TQFN-16_L3.0-W3.0-P0.50-BL-EP1.5; MPN MAX98357AETE+T; LCSC Part # C910544

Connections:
+5V: NT1.1; also elsewhere on the board
/Audio/AUDIO_5V: C3.2, JP1.1 (A), NT1.2, R12.1, U3.7 (VDD), U3.8 (VDD)
/I2S_BCLK: U3.16 (BCLK); also elsewhere on the board
/I2S_DIN: U3.1 (DIN); also elsewhere on the board
/I2S_LRC: U3.14 (LRCLK); also elsewhere on the board
GND: C3.1, U3.3 (GND), U3.11 (GND), U3.15 (GND), U3.17 (EP); also elsewhere on the board
unnamed: J1.1, TP1.1 (1_1), U3.10 (OUTN)
unnamed: J1.2, TP2.1 (1_1), U3.9 (OUTP)
unnamed: JP1.2 (B), U3.2 (GAIN_SLOT)
unnamed: R12.2, U3.4 (~SD_MODE)

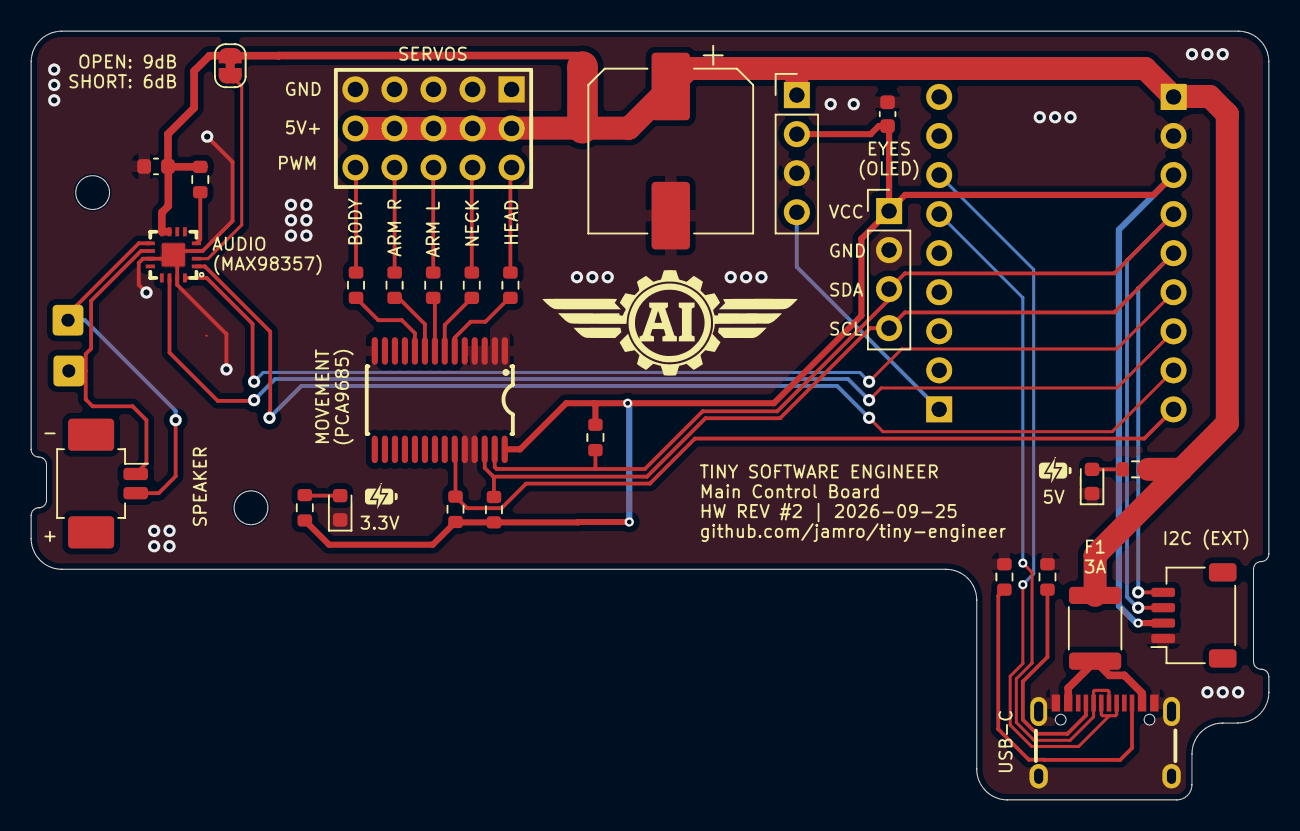
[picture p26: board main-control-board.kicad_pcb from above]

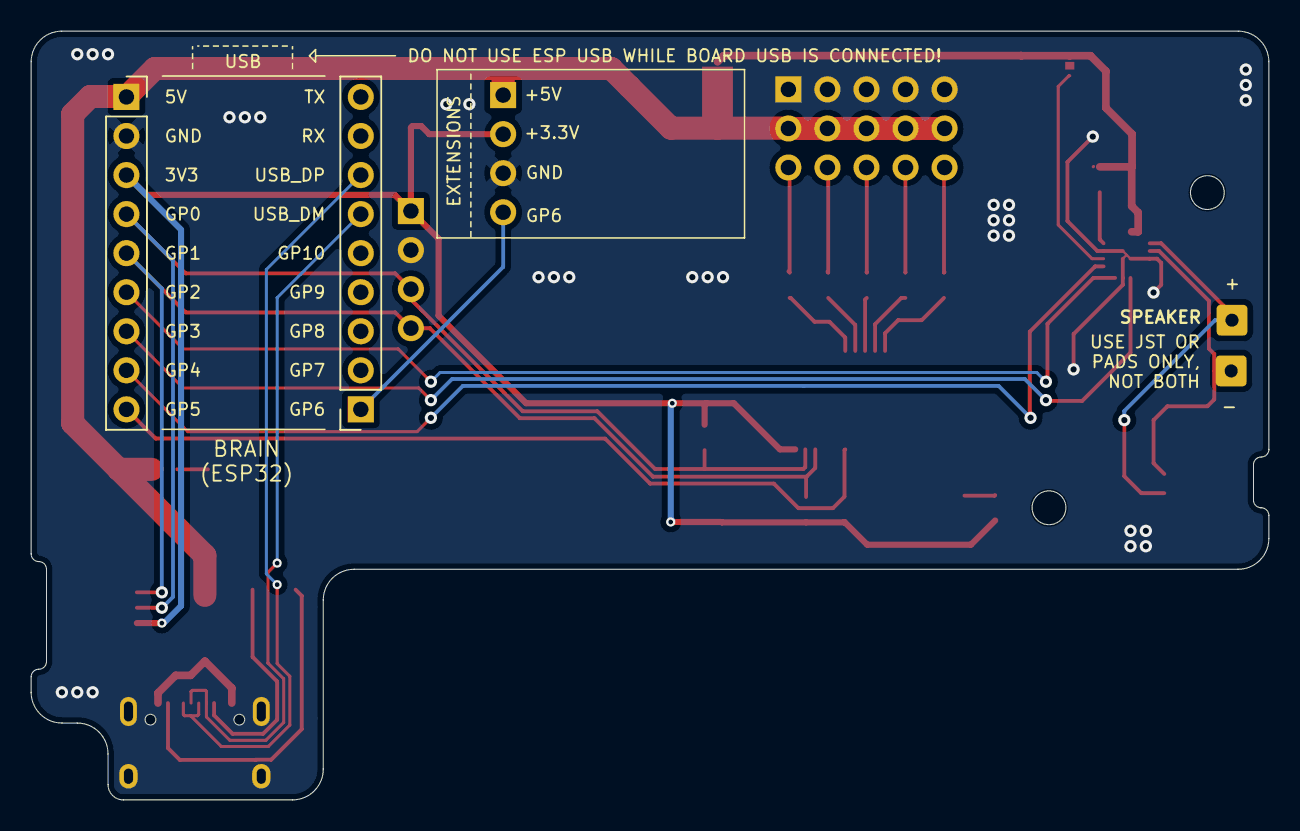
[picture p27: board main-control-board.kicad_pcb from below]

Board: 2 copper layers, 80.5 x 50.0 mm, 35 parts (2 on the bottom side), 32 nets.

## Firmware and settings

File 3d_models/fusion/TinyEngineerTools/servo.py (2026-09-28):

"""Servo model picker. Writes dimensions into Fusion user parameters."""

import json
import os
import traceback

import adsk.core
import adsk.fusion

app = adsk.core.Application.get()
ui = app.userInterface

COMMAND_ID = 'TinyEngineerTools'
COMMAND_NAME = 'TinyEngineer Servo Configurator'
COMMAND_DESCRIPTION = 'Select servo model and apply dimensions'
WORKSPACE_ID = 'FusionSolidEnvironment'
PANEL_ID = 'SolidScriptsAddinsPanel'
SERVO_ID_PARAM = 'servo_id'
KEYBOARD_SKETCH = 'keyboard'

_handlers = []


def start():
    cmd_def = ui.commandDefinitions.itemById(COMMAND_ID)
    if not cmd_def:
        cmd_def = ui.commandDefinitions.addButtonDefinition(
            COMMAND_ID, COMMAND_NAME, COMMAND_DESCRIPTION
        )

    created = CommandCreatedHandler()
    cmd_def.commandCreated.add(created)
    _handlers.append(created)

    workspace = ui.workspaces.itemById(WORKSPACE_ID)
    if not workspace:
        ui.messageBox(f'Workspace not found: {WORKSPACE_ID}')
        return

    panel = workspace.toolbarPanels.itemById(PANEL_ID)
    if not panel:
        ui.messageBox(f'Toolbar panel not found: {PANEL_ID}')
        return

    control = panel.controls.itemById(COMMAND_ID)
    if not control:
        control = panel.controls.addCommand(cmd_def)

    control.isPromoted = True
    control.isPromotedByDefault = True


def stop():
    workspace = ui.workspaces.itemById(WORKSPACE_ID)
    if workspace:
        panel = workspace.toolbarPanels.itemById(PANEL_ID)
        if panel:
            control = panel.controls.itemById(COMMAND_ID)
            if control:
                control.deleteMe()

    cmd_def = ui.commandDefinitions.itemById(COMMAND_ID)
    if cmd_def:
        cmd_def.deleteMe()

    _handlers.clear()


def _load_servos():
    path = os.path.join(os.path.dirname(os.path.abspath(__file__)), 'servos.json')
    with open(path, encoding='utf-8') as file:
        return json.load(file)


def _display_name(parameter_name):
    if parameter_name.startswith('servo_'):
        parameter_name = parameter_name[len('servo_'):]
    return parameter_name.replace('_', ' ').title()


def _selected_servo(inputs, servos):
    dropdown = adsk.core.DropDownCommandInput.cast(
        inputs.itemById('servo_model')
    )
    if not dropdown or not dropdown.selectedItem:
        return None
    return servos[dropdown.selectedItem.name]


def _update_preview(inputs, servos):
    servo = _selected_servo(inputs, servos)
    if not servo:
        return

    for parameter_name, value in servo.items():
        preview = adsk.core.TextBoxCommandInput.cast(
            inputs.itemById(f'preview_{parameter_name}')
        )
        if preview:
            preview.text = value


def _build_dialog(inputs, servos):
    dropdown = inputs.addDropDownCommandInput(
        'servo_model',
        'Servo model',
        adsk.core.DropDownStyles.TextListDropDownStyle,
    )
    for index, servo_name in enumerate(servos):
        dropdown.listItems.add(servo_name, index == 0, '')

    first_servo = next(iter(servos.values()))
    for parameter_name in first_servo:
        inputs.addTextBoxCommandInput(
            f'preview_{parameter_name}',
            _display_name(parameter_name),
            '',
            1,
            True,
        )

    _update_preview(inputs, servos)


def _apply_servo_id(params, value):
    existing = params.itemByName(SERVO_ID_PARAM)
    if existing:
        try:
            existing.textValue = value
            return
        except Exception:
            pass
        try:
            existing.expression = f"'{value}'"
            return
        except Exception:
            existing.deleteMe()

    params.add(
        SERVO_ID_PARAM,
        adsk.core.ValueInput.createByString(f"'{value}'"),
        'Text',
        'Selected servo id',
    )


def _apply_servo(design, servo_data, show_errors=True):
    """Apply servo_data to design user parameters. Returns True on success."""
    params = design.userParameters
    dimensions = {
        name: value
        for name, value in servo_data.items()
        if name != SERVO_ID_PARAM
    }
    missing = [name for name in dimensions if not params.itemByName(name)]
    if missing:
        if show_errors:
            ui.messageBox(
                'The following Fusion parameters do not exist:\n\n'
                + '\n'.join(missing)
            )
        return False

    servo_id = servo_data.get(SERVO_ID_PARAM)
    if servo_id:
        _apply_servo_id(params, servo_id)

    to_set = []
    values = []
    for name, value in dimensions.items():
        to_set.append(params.itemByName(name))
        values.append(adsk.core.ValueInput.createByString(value))

    if not design.modifyParameters(to_set, values):
        if show_errors:
            ui.messageBox('Failed to set servo parameters.')
        return False

    design.computeAll()
    fix_keyboard_cut(design)
    return True


def _profiles(extrude):
    """Sketch profiles an extrude uses (skips sketch text and faces)."""
    try:
        selection = extrude.profile
    except Exception:
        return []
    items = [selection]
    if not adsk.fusion.Profile.cast(selection) and hasattr(selection, 'count'):
        items = [selection.item(i) for i in range(selection.count)]
    return [p for p in map(adsk.fusion.Profile.cast, items) if p]


def _keyboard_cut(design):
    """Return (sketch, extrude) for the cut that uses the keyboard sketch."""
    for component in design.allComponents:
        sketch = component.sketches.itemByName(KEYBOARD_SKETCH)
        if not sketch:
            continue
        for extrude in component.features.extrudeFeatures:
            profiles = _profiles(extrude)
            if profiles and profiles[0].parentSketch.name == KEYBOARD_SKETCH:
                return sketch, extrude
    return None, None


def fix_keyboard_cut(design):
    """Re-select the keyboard cut profile after a servo size change.

    The extrude on the `keyboard` sketch cuts the deck region around the
    keys: one profile whose inner loops are the key outlines. When the key
    grid grows, Fusion also maps the new key profiles into that cut, so those
    keys vanish (#31). Reset the selection to the profile with the most loops.
    Returns True when the selection was changed.
    """
    sketch, extrude = _keyboard_cut(design)
    if not extrude or sketch.profiles.count == 0:
        return False

    deck_loops = max(p.profileLoops.count for p in sketch.profiles)
    selected = _profiles(extrude)
    if len(selected) == 1 and selected[0].profileLoops.count == deck_loops:
        return False

    timeline = design.timeline
    marker = timeline.markerPosition
    extrude.timelineObject.rollTo(True)
    try:
        extrude.profile = max(
            sketch.profiles, key=lambda p: p.profileLoops.count
        )
    finally:
        timeline.markerPosition = marker
    design.computeAll()
    return True
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

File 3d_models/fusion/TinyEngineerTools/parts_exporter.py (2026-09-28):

"""Export PRINT_LAYOUT children as 3MF, binary STL, and STEP."""

import os
import traceback

import adsk
import adsk.core
import adsk.fusion

import servo

app = adsk.core.Application.get()
ui = app.userInterface

COMMAND_ID = 'TinyEngineerPartsExporter'
COMMAND_NAME = 'Tiny Engineer Parts Exporter'
COMMAND_DESCRIPTION = 'Export PRINT_LAYOUT children as 3MF, binary STL, and STEP'
WORKSPACE_ID = 'FusionSolidEnvironment'
PANEL_ID = 'SolidScriptsAddinsPanel'
PRINT_LAYOUT_NAME = 'PRINT_LAYOUT'
_INVALID_FILENAME_CHARS = '<>:"/\\|?*'
PARTS_TABLE_ID = 'parts_table'
SELECT_ALL_ID = 'select_all'
DESELECT_ALL_ID = 'deselect_all'
EXPORT_3MF_ID = 'export_3mf'
EXPORT_STL_ID = 'export_stl'
EXPORT_STEP_ID = 'export_step'
PARTS_VISIBLE_ROWS = 12

_handlers = []


def start():
    cmd_def = ui.commandDefinitions.itemById(COMMAND_ID)
    if not cmd_def:
        cmd_def = ui.commandDefinitions.addButtonDefinition(
            COMMAND_ID, COMMAND_NAME, COMMAND_DESCRIPTION
        )

    created = CommandCreatedHandler()
    cmd_def.commandCreated.add(created)
    _handlers.append(created)

    workspace = ui.workspaces.itemById(WORKSPACE_ID)
    if not workspace:
        ui.messageBox(f'Workspace not found: {WORKSPACE_ID}')
        return

    panel = workspace.toolbarPanels.itemById(PANEL_ID)
    if not panel:
        ui.messageBox(f'Toolbar panel not found: {PANEL_ID}')
        return

    control = panel.controls.itemById(COMMAND_ID)
    if not control:
        control = panel.controls.addCommand(cmd_def, servo.COMMAND_ID, False)

    control.isPromoted = True
    control.isPromotedByDefault = True


def stop():
    workspace = ui.workspaces.itemById(WORKSPACE_ID)
    if workspace:
        panel = workspace.toolbarPanels.itemById(PANEL_ID)
        if panel:
            control = panel.controls.itemById(COMMAND_ID)
            if control:
                control.deleteMe()

    cmd_def = ui.commandDefinitions.itemById(COMMAND_ID)
    if cmd_def:
        cmd_def.deleteMe()

    _handlers.clear()


def _error(title):
    ui.messageBox(f'{title}:\n\n{traceback.format_exc()}')


def _safe_filename(name):
    cleaned = ''.join('_' if ch in _INVALID_FILENAME_CHARS else ch for ch in name)
    cleaned = cleaned.strip().rstrip('.')
    return cleaned or 'part'


def _unique_base(occ, used):
    base = _safe_filename(occ.component.name)
    if base not in used:
        used.add(base)
        return base

    suffixed = _safe_filename(f'{occ.component.name}_{occ.name}')
    candidate = suffixed
    index = 2
    while candidate in used:
        candidate = f'{suffixed}_{index}'
        index += 1
    used.add(candidate)
    return candidate


def _occurrence_list(occurrences):
    if not occurrences:
        return []
    return [occurrences.item(i) for i in range(occurrences.count)]


def _find_print_layout(design):
    root = design.rootComponent
    if root.name == PRINT_LAYOUT_NAME:
        return root, _occurrence_list(root.occurrences), root

    for occ in root.allOccurrences:
        if occ.component.name == PRINT_LAYOUT_NAME:
            return occ, _occurrence_list(occ.childOccurrences), occ.component

    return None, None, None


def _body_list(component):
    bodies = component.bRepBodies
    if not bodies:
        return []
    return [bodies.item(i) for i in range(bodies.count)]


def _descendant_occurrences(occ):
    result = []
    for child in _occurrence_list(occ.childOccurrences):
        result.append(child)
        result.extend(_descendant_occurrences(child))
    return result


def _set_child_visible(children, visible_occ):
    for occ in children:
        occ.isLightBulbOn = False
    if visible_occ:
        visible_occ.isLightBulbOn = True
        for desc in _descendant_occurrences(visible_occ):
            desc.isLightBulbOn = True


def _occurrence_ancestors(occ):
    chain = []
    current = occ
    while current:
        chain.append(current)
        current = current.assemblyContext
    return chain


def _restore_visibility(occ_state, body_state, layout_component, folder_on):
    for occ, was_on in occ_state:
        occ.isLightBulbOn = was_on
    for body, was_on in body_state:
        body.isLightBulbOn = was_on
    layout_component.isBodiesFolderLightBulbOn = folder_on


def _write_servo_readme(servo_dir, title, data):
    lines = [f'# {title}', '']
    for key, value in data.items():
        lines.append(f'- `{key}`: {value}')
    lines.append('')
    with open(os.path.join(servo_dir, 'README.md'), 'w', encoding='utf-8') as file:
        file.write('\n'.join(lines))


def _choose_folder():
    dialog = ui.createFolderDialog()
    dialog.title = 'Select export folder'
    if dialog.showDialog() != adsk.core.DialogResults.DialogOK:
        return None
    return dialog.folder


def _export_dirs(folder, servo_id, want_stl, want_3mf, want_step):
    servo_dir = os.path.join(folder, servo_id)
    stl_dir = os.path.join(servo_dir, 'stl') if want_stl else None
    c3mf_dir = os.path.join(servo_dir, '3mf') if want_3mf else None
    step_dir = os.path.join(servo_dir, 'step') if want_step else None
    os.makedirs(servo_dir, exist_ok=True)
    if stl_dir:
        os.makedirs(stl_dir, exist_ok=True)
    if c3mf_dir:
        os.makedirs(c3mf_dir, exist_ok=True)
    if step_dir:
        os.makedirs(step_dir, exist_ok=True)
    return servo_dir, stl_dir, c3mf_dir, step_dir


def _export_stl(export_mgr, geometry, stl_dir, base):
    try:
        stl = export_mgr.createSTLExportOptions(
            geometry, os.path.join(stl_dir, f'{base}.stl')
        )
        stl.isBinaryFormat = True
        stl.sendToPrintUtility = False
        export_mgr.execute(stl)
        return []
    except Exception as exc:
        return [f'{base}.stl: {exc}']


def _export_3mf(export_mgr, geometry, c3mf_dir, base):
    try:
        c3mf = export_mgr.createC3MFExportOptions(
            geometry, os.path.join(c3mf_dir, f'{base}.3mf')
        )
        c3mf.sendToPrintUtility = False
        export_mgr.execute(c3mf)
        return []
    except Exception as exc:
        return [f'{base}.3mf: {exc}']


def _step_component(geometry):
    component = adsk.fusion.Component.cast(geometry)
    if component:
        return component
    occ = adsk.fusion.Occurrence.cast(geometry)
    if occ:
        return occ.component
    return None
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

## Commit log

2026-09-28 design pumpkin head v1 - pre-test
    [TinyEngineerHalloween.f3d]
2026-09-28 feat(mod): add custom halloween lamp and mug models
    [Head.3mf, Head.step, Head.stl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]
2026-09-28 refactor(mods): move mods to the repo root
    Keep each mod's CAD and exports under 3d_models so other files can live beside the models.
    [Head.3mf, Head.step, Head.stl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]
2026-09-28 feat: overlay mod audio on stock clips
    Pack stock WAVs, then replace only the files a mod ships. Cue sidecars follow the new lines, and a larger LittleFS image fits the Halloween set.
    [partitions.csv]
2026-09-28 reshape the board to mount SDM USB
    [main-control-board.kicad_pcb, main-control-board.kicad_sch]
2026-09-28 use hierarchical sheets in schmatic
    [main-control-board-esp32.kicad_sch, main-control-board-pca.kicad_sch, main-control-board-usb-audio.kicad_sch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]
2026-09-28 integrate PCA into the board
    [main-control-board-esp32.kicad_sch, main-control-board-pca.kicad_sch, main-control-board-usb.kicad_sch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]
2026-09-28 add power indicator
    [main-control-board-usb.kicad_sch, main-control-board.kicad_pcb]
2026-09-28 set FT Rotation Offset to fix JLCPCB orientation
    [main-control-board-esp32.kicad_sch, main-control-board-pca.kicad_sch, main-control-board.kicad_pcb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]
2026-09-28 integrate audio module
    [main-control-board-usb-audio.kicad_sch, main-control-board.kicad_pcb]
2026-09-28 improve board visuals
    [main-control-board-usb-audio.kicad_sch, main-control-board.kicad_pcb]
2026-09-28 add I2C extension port
    [main-control-board-usb-audio.kicad_sch, main-control-board.kicad_pcb, main-control-board.kicad_sch]
2026-09-28 use basic components over extended
    [main-control-board-pca.kicad_sch, main-control-board-usb-audio.kicad_sch, main-control-board-usb.kicad_sch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]
2026-09-28 add polyfuse protection
    [main-control-board-usb-audio.kicad_sch, main-control-board-usb.kicad_sch, main-control-board.kicad_pcb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]
2026-09-28 turn test points into extension points
    [main-control-board-esp32.kicad_sch, main-control-board.kicad_pcb, main-control-board.kicad_sch]
2026-09-28 pre-fab improvements
    [main-control-board-esp32.kicad_sch, main-control-board-pca.kicad_sch, main-control-board-usb-audio.kicad_sch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]
2026-09-28 fix(cad): keep laptop keys when switching to a larger servo
    The cut on the `keyboard` sketch uses one profile: the deck, with the key
    outlines as holes. After switching from a smaller to a larger servo,
    Fusion added the new key profiles to that cut, so those keys were cut
    away (SG90 after FS0307: 61 keys instead of 67).
    fix_keyboard_cut() finds that extrude by its sketch and re-selects the
    deck profile (the one with the most loops) after every servo change: in
    the Servo Configurator, in the Parts Exporter, and when the exporter
    restores the previous parameters. It does nothing when the selection is
    already correct and keeps the timeline marker where it was.
    Fixes #31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
    [parts_exporter.py, servo.py]
2026-09-30 docs: add my color variants and filament list
    Preview images recolored from a photo of the original build, plus the
    part-to-color mapping and filament shopping list for variant 2.
2026-09-30 docs: add swatch set to my filament list
2026-09-30 feat(cad): add I love IT mug parts and lamp colors to my build
    [Tasse_Henkel.stl, Tasse_Herz.stl, Tasse_ILoveIT_Teile.3mf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]
2026-09-30 feat(cad): split desk color under the chair, lamp diffuser in natural PLA
    [Tisch_Farbtrennung_Teile.3mf]
2026-09-30 feat(cad): thin transparent blue bottom layer on the desk top
    [Tischplatte_Blauschicht_Teile.3mf]
2026-09-30 docs: realistic preview of the current color scheme
2026-09-30 feat(cad): console text on the laptop screen
    [Bildschirm_Konsole_Teile.3mf]
2026-09-30 feat(cad): desk in PETG RAL 7016, generic hello console
    [Bildschirm_Konsole_Teile.3mf]
2026-09-30 feat(cad): console greets with Hello human
    [Bildschirm_Konsole_Teile.3mf]
2026-09-30 docs: final color plan - desk all RAL 7016, white mug handle
    [Tasse_Henkel.stl, Tasse_ILoveIT_Teile.3mf, Tasse_Tasse.stl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]
2026-10-01 feat(cad): ready-to-print Bambu Studio projects for three robots
    [TinyEngineer_01_Testteile.3mf, TinyEngineer_02_Weiss_Roboter_1.3mf, TinyEngineer_02_Weiss_Roboter_2.3mf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]
2026-10-01 feat(cad): print projects for an original and a Variante-2 robot
    Replace the three-robot set with plates for two robots printed together:
    robot 1 in the original colours (PETG Burnt Copper, black PLA, white
    diffuser) and robot 2 in Variante 2. Same-colour parts of both robots
    share a plate; mug and console screen share one multicolour plate.
    Update the dasfilament order for two robots.
    [TinyEngineer_01_Testteile.3mf, TinyEngineer_02_Weiss.3mf, TinyEngineer_02_Weiss_Roboter_1.3mf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]
2026-10-01 feat(cad): console screen for the original robot too
    Robot 1 (original colours) gets the console screen instead of the plain
    black LaptopScreen; both console screens print on plate 08 with the mug.
    [TinyEngineer_03_Schwarz_1.3mf, TinyEngineer_03_Schwarz_2.3mf, TinyEngineer_08_Tasse_Bildschirm.3mf]
2026-10-01 docs: Session-Handover 2026-10-02 — Druckprojekte 2 Bots, offene Punkte
